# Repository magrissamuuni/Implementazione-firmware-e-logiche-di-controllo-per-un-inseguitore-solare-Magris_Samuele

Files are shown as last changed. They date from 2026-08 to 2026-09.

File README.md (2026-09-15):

Progetto sviluppato nell'ambito della tesi di laurea triennale
Dipartimento di Ingegneria dell'Informazione, Università degli Studi di Padova. 
Relatore: Prof. Damiano Varagnolo.

## Indice

- [Introduzione](#introduzione)
- [Obiettivi](#obiettivi)
- [Progettazione 3D](#progettazione-3d)
- [Hardware](#hardware)
- [Firmware](#firmware)
- [Interfaccia web](#interfaccia-web)
- [Prototipo](#prototipo)
- [Stampa Definitiva](#stampa-definitiva)
- [Metodologia sperimentale](#metodologia-sperimentale)
- [Design of Experiments](#design-of-experiments)
- [Confronto](#confronto)
- [Documentazione](#documentazione)
## Introduzione
Le fonti rinnovabili di energia sono viste come un'alternativa affidabile ai combustibili fossili grazie alla loro capacità di essere inesauribili.
L'energia solare fotovoltaica è una delle fonti rinnovabili più a portata di mano rispetto all'energia geotermica, idrica, bioenergia oppure eolica.
Massimizzare il tempo passato perpendicolarmente al sole è uno dei metodi migliori per massimizzare l'efficienza di un pannello fotovoltaico
(dimostrabile secondo la formula $$P = G \cdot A \cdot \eta \cdot \cos(\theta)$$)

Per fare ciò, sistemi di tracciamento permettono ai pannelli solari di rimanere perpendicolari ai raggi solari per la maggior parte della giornata.
Lo scopo di questo progetto è quello di sviluppare un prototipo bi-assiale a scala ridotta di un sistema di tracciamento solare mediante l'uso di fotoresistenze per tracciare la posizione del sole.

## Obiettivi

L'obiettivo è quello di creare un sistema indipendente in grado di autosostenersi.
Il sistema deve essere in grado di:
- riconoscere la posizione del punto di massima luminosità e orientare il pannello verso di esso;
- evitare micro-movimenti una volta raggiunto tale punto (causati da valori diversi sulle fotoresistenze).

Il firmware deve:
- implementare una interfaccia per l'utilizzo del sistema;
- implementare un controllore PID e permetterne la modifica dei parametri;
- raccogliere le informazioni e i dati riguardo a: errori dei servomotori, luminosità delle fotoresistenze e parametri dei pannelli fotovoltaici;
- gestire il movimento dei servo-motori;

## Progettazione 3D
Il sistema meccanico è stato progettato tramite l'utilizzo di Fusion 360.
E' progettato per permettere l'utilizzo di due servomotori SG90 che consentono il movimento bi-assiale. Per ricavare i dati di puntamento tramite le fotoresistenze è stata realizzata una struttura a croce che proietta un'ombra sulle LDR: quando il pannello è orientato perpendicolarmente al sole, l'ombra cade in modo simmetrico su tutti e quattro i sensori, azzerando la differenza di illuminamento tra loro:

Il sistema composto da:
- un ingranaggio con due strutture a forcella;
  <br>
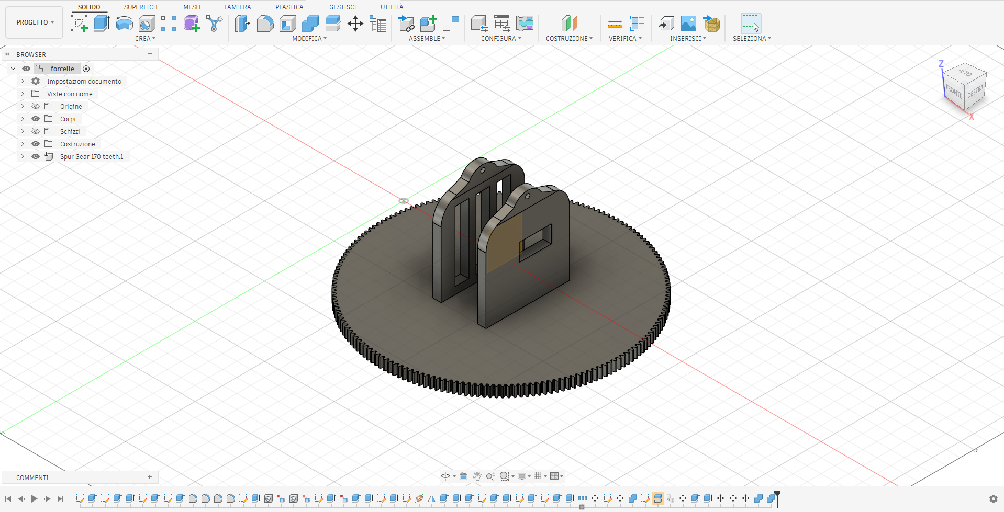
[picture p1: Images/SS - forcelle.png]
  
- una croce per permettere di proiettare ombre sulle LDR;
  <br>
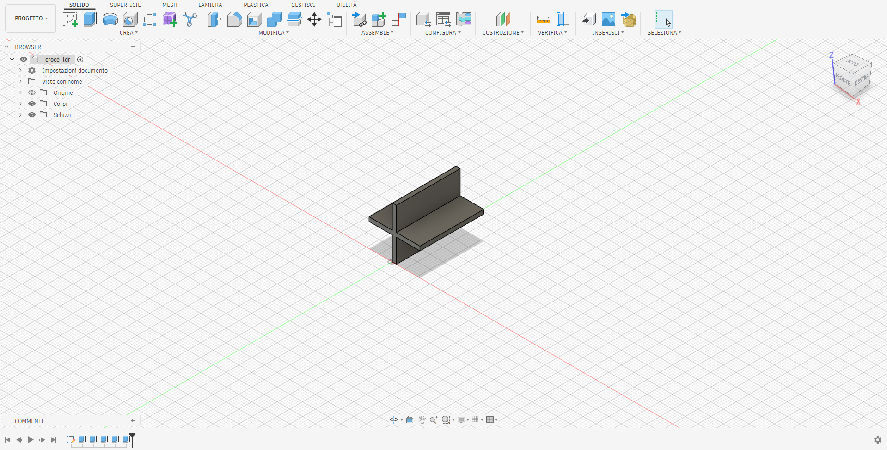
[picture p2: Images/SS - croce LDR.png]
  
- due pignoni, che collegano li SG90 al resto della struttura;
  <br>
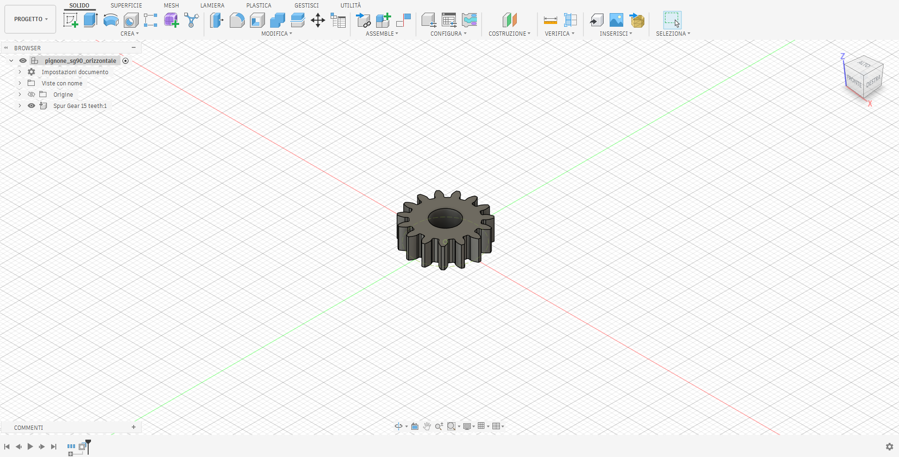
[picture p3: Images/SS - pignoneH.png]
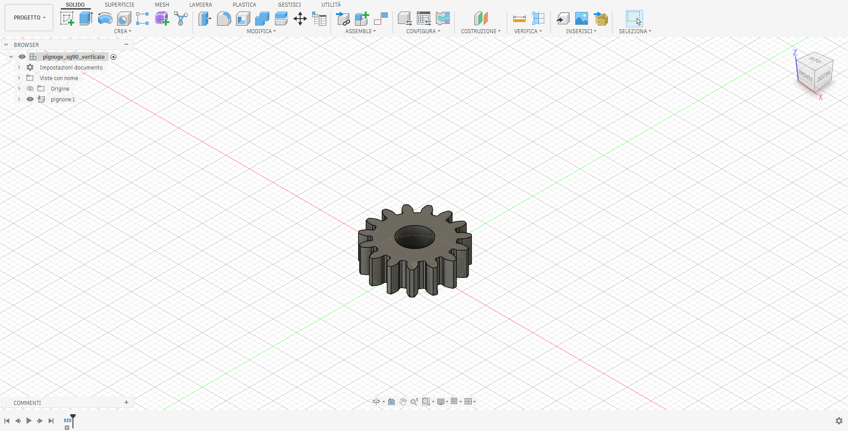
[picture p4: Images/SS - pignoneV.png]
     
- una struttura rettangolare dove risiede il pannello;
  <br>
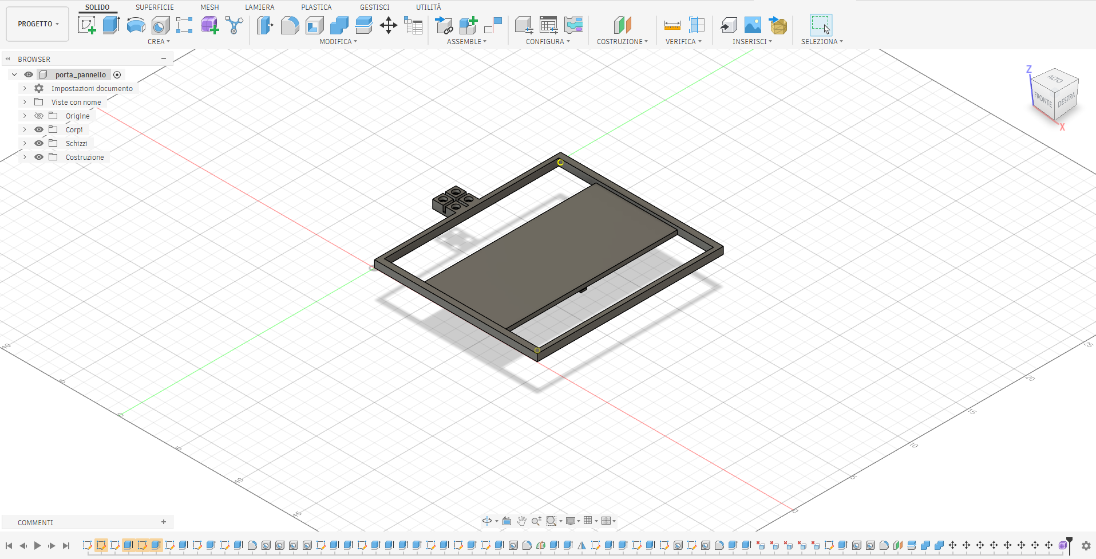
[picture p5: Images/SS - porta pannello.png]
    
- un semi-ingranaggio;
  <br>
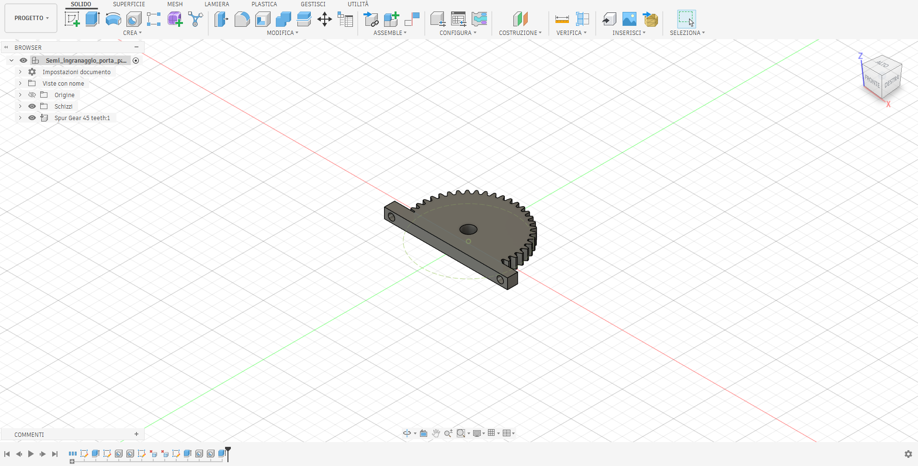
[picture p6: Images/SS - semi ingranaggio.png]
  
- una struttura di base. su cui poggia l'intero sistema.
  <br>
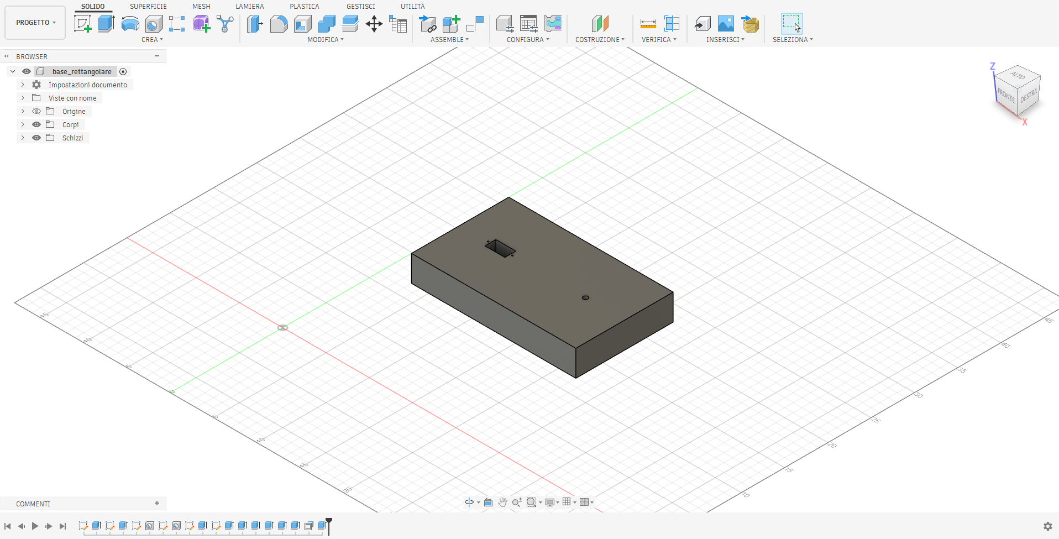
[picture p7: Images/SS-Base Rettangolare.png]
    

## Hardware

- Microcontrollore: ESP32 WROOM [ESP32](DataSheet/esp32-wroom-32_datasheet_en.pdf)
- Sensori: 4 fotoresistenze (LDR) [LDR](DataSheet/GL55-LDR%20DataSheet.pdf)
- Attuatori: 2 servomotori [SG90](DataSheet/SG90%20DataSheet.pdf)
- Batteria: 1 batteria ricaricabile al litio [103450](DataSheet/Battery%203.7%20V%202000mAh%20103450%20DataSheet.pdf)
- Ricarica e protezione: 1 modulo di ricarica con 1 chip di protezione [TP5046](DataSheet/TP4056%20(modulo%20ricarica)%20DataSheet.pdf) [DW01A](DataSheet/DW01A%20(chip%20protezione)%20DataSheet.pdf)
- Lettore Voltaggio/Corrente: [INA219](DataSheet/ina219%20(current%20power%20monitor)%20DataSheet.pdf)
- Modulo Step-UP: 1 modulo [MT3608](DataSheet/MT3608%20(step%20up)%20DataSheet.pdf)
- Pannello solare: 5V

Il circuito è alimentato da un pannello solare in silicio policristallino da 5V con potenza massima erogabile di 2.5W. Questo è collegato ad un modulo di ricarica TP4056 che permette la ricarica di una batteria LiPo 3.7V 2000mAh

Un convertitore step-up MT3608 porta la tensione della batteria al livello richiesto dal circuito ovvero 5V. Quest’ultimo alimenta l’ESP32 e quindi l’intero circuito

Sono state utilizzate 4 fotoresistenze (LDR) per rilevare la posizione del sole. Tramite l’ESP32 le fotoresistenze indicavano al sistema dove posizionarsi tramite l’utilizzo di due servomotori SG90

### Mappa dei pin

- Servo orizzontale (H) = 19
- Servo verticale (V) = 18 
- LDR Alto-Sinistra (TL) = 35
- LDR Alto-Destra (TR) = 33
- LDR Basso-Sinistra (BL) = 34
- LDR Basso-Destra (BR) = 32
- Tensione pannello solare = 36

## Firmware

File: [`src/main.cpp`](src/main.cpp) + [`include/webpage.h`](include/webpage.h)

### Librerie richieste (Arduino IDE / PlatformIO)

- `WiFi.h`, `WebServer.h`, `Preferences.h`
- `ESP32Servo`
- `PID_v1`

### Funzionalità principali

- Controllo PID reale su entrambi gli assi
- Autotuning automatico dei guadagni PID via relay feedback
  (metodo di Åström–Hägglund + formule di Ziegler-Nichols)
- Calibrazione automatica dei 4 sensori LDR
- Logging su buffer con esportazione CSV
- Persistenza dei parametri in NVS

### Come Avviare

1. Apri `firmware/main.cpp` in Arduino IDE o PlatformIO
2. Installa le librerie elencate sopra dal Library Manager
3. Seleziona la scheda ESP32 corretta e la porta seriale
4. Carica il firmware

All'avvio l'ESP32 crea una rete Wi-Fi propria:

- **SSID**: `SolarTracker-ESP32`
- **Password**: `12345678`

## Interfaccia web

Connettiti alla rete Wi-Fi del tracker e apri `http://192.168.4.1` dal
browser. L'interfaccia mostra in tempo reale: telemetria del pannello solare,
letture dei 4 LDR, stato del controllo PID, e permette di cambiare modalità,
controllare manualmente i motori, tarare il PID, calibrare i sensori e
scaricare i log come CSV.

## Prototipo

Il sistema è stato inizialmente stampato in  PLA, il quale inizia a subire deformazioni strutturali e a perdere la propria rigidità geometrica già all’interno dell’intervallo termico compreso tra i 50 °C e i 60 °C. 
Si è quindi optato per il PETG, in grado di garantire una stabilità dimensionale anche in condizioni di calore moderato (fino ai 70 °C  - 75°C) superando così i limiti del PLA. Inoltre, presenta una maggiore opacità alla luce rispetto al PLA.

Il circuito è stato assemblato e saldato manualmente con alcuni errori di collegamento verificatisi e successivamente corretti.
E' stato successivamente validato funzionalmente prima dei test firmware.

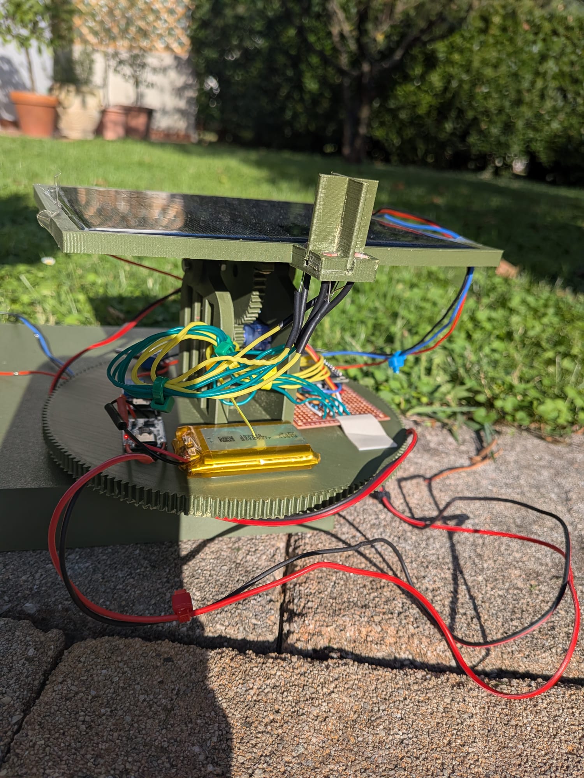
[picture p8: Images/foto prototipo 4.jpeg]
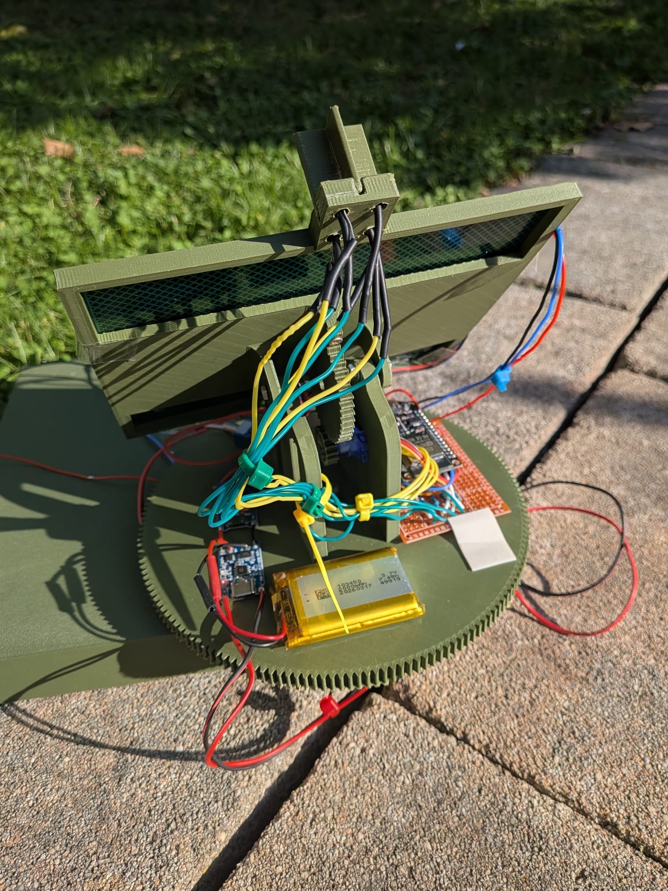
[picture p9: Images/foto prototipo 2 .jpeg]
 
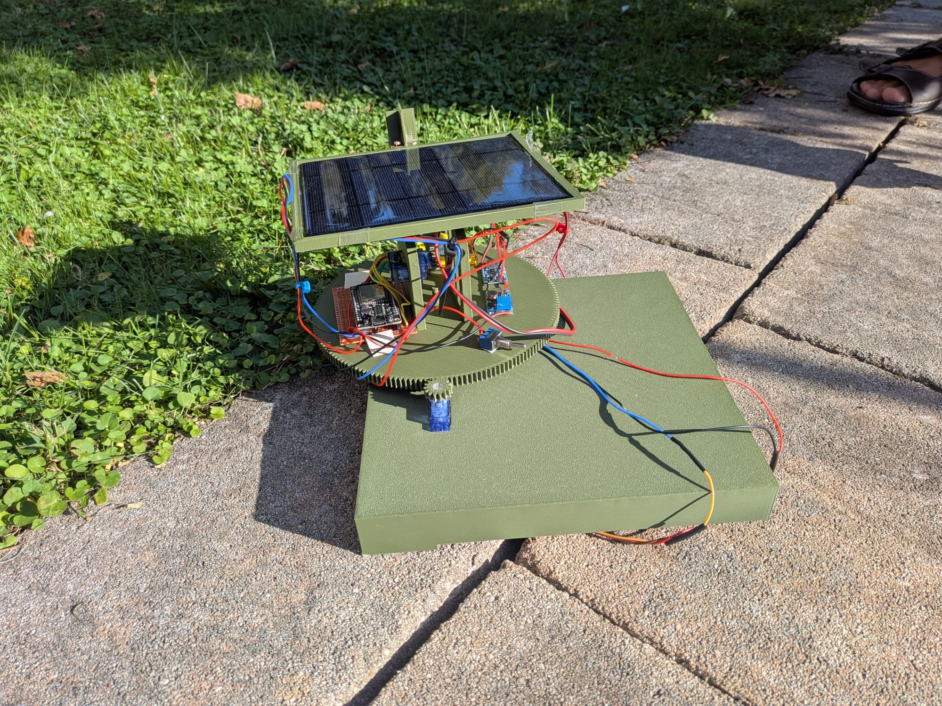
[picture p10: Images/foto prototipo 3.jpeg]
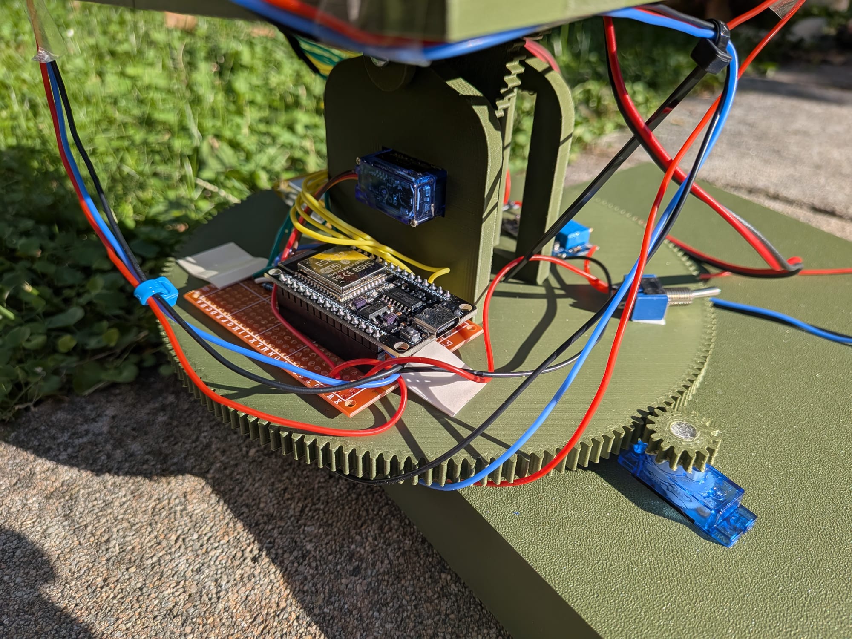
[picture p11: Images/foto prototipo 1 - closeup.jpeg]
 

Il sistema risulta funzionale ma non esponibile al sola dato il materiale utilizzato. Occorre quindi una ristampa.

## Stampa Definitiva
La versione finale è stata stampata in PETG e non ha più presentato i problemi di deformazione termica riscontrati con il PLA, confermando la stabilità strutturale della soluzione adottata. <br> <br>
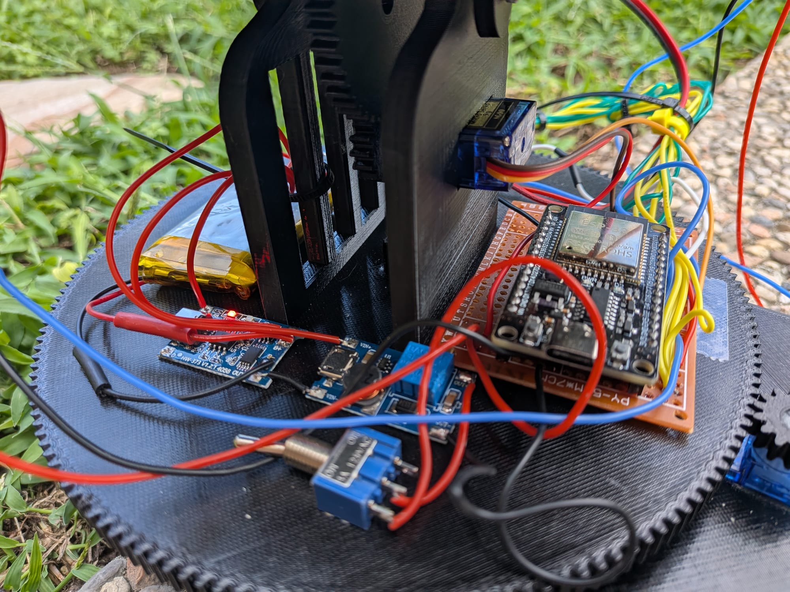
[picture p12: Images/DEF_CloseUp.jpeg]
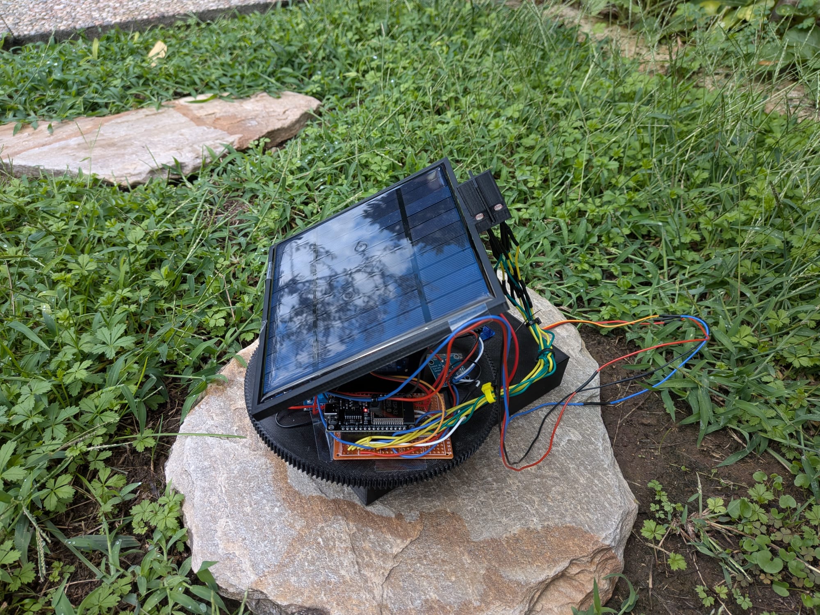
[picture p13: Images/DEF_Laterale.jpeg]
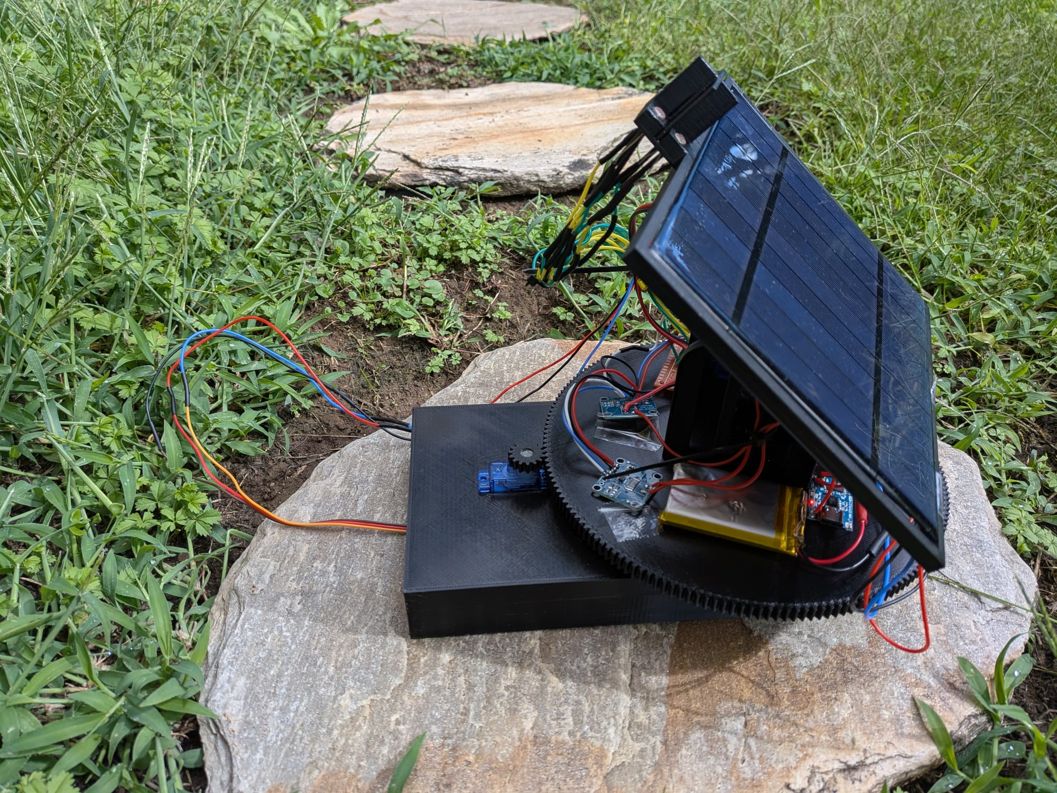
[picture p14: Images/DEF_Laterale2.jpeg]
   

## Metodologia sperimentale

I guadagni PID (Kp/Ki/Kd) **non** sono variabili sperimentali del DOE: sono
tarati a parte tramite il metodo di Åström-Hägglund. Da questo otteniamo:

$$K_u = \frac{1}{|G(j\omega_u)|} = \frac{4d}{\pi a}$$

$$P_u = \frac{2\pi}{\omega_u}$$

Tramite le tabelle di Ziegler-Nichols:

$$K_p = 0.6K_u \qquad T_i = \frac{P_u}{2} \qquad T_d = \frac{P_u}{8}$$

$$K_p = 0.6K_u \qquad K_i = \frac{2K_p}{P_u} \qquad K_d = \frac{K_p P_u}{8}$$

A differenza dei modelli teorici in tempo continuo, il microcontrollore elabora i segnali dei sensori a intervalli di tempo regolari e definiti (tempo di campionamento 𝑇𝑠=50𝑚𝑠)

## Design of Experiments

| Variabile | ANOVA F | ANOVA p | Pendenza | R² | Regressione p |
|---|---|---|---|---|---|
| Errore residuo H | 2.319 | 0.112 | +0.075 | 0.024 | 0.328 |
| Errore residuo V | 2.329 | 0.111 | +0.010 | 0.001 | 0.884 |
| Overshoot H | 1.940 | 0.157 | −0.435 | 0.037 | 0.222 |
| Overshoot V | 0.913 | 0.410 | +0.123 | 0.007 | 0.609 |
| Tempo di assestamento H | 2.389 | 0.105 | −50.68 | 0.079 | 0.072 |
| Tempo di assestamento V | 1.601 | 0.215 | −42.82 | 0.069 | 0.092 |

Nessuna delle variabili di risposta ha raggiunto la soglia di significatività, né tramite ANOVA né tramite regressione lineare.
Nonostante il disegno sperimentale esteso fosse dimensionato per garantire l'80% di potenza rispetto all'effetto stimato nella fase preliminare, l'effetto osservato nel campione esteso è risultato sostanzialmente più piccolo della stima iniziale. 
<br>
Due sensori LDR saturano al valore massimo e il comportamento è coerente con un sottodimensionamento del partitore resistivo che non garantisce un margine sufficiente in condizioni di elevata luminosità.
Con due sensori bloccati allo stesso valore le formule di errore si riducono algebricamente in modo tale che errore H ed errore V diventano l'uno l'esatto opposto dell'altro

## Confronto

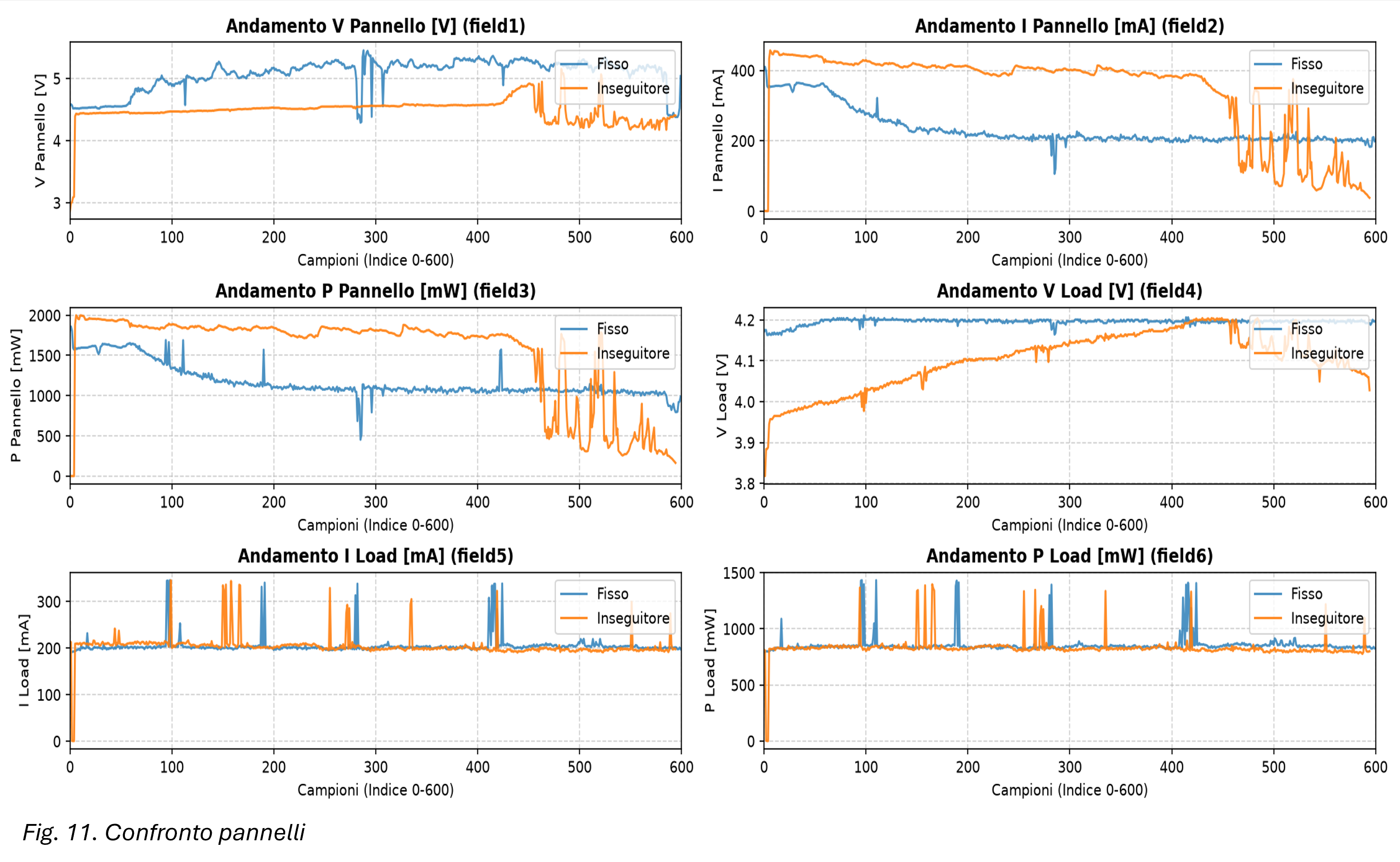
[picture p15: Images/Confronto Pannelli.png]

L'inseguimento biassiale garantisce un'erogazione media di 1.8 W - 2.0 W, incrementando la resa rispetto all'installazione statica di circa il 50-70% nello stesso intervallo.
In entrambi i casi il consumo del carico è il medesimo. 
I campioni 450-600 dell’inseguitore riflettono un annuvolamento avvenuto durante la raccolta dati.

## Documentazione
[ESP32](DataSheet/esp32-wroom-32_datasheet_en.pdf)
[LDR](DataSheet/GL55-LDR%20DataSheet.pdf)
[SG90](DataSheet/SG90%20DataSheet.pdf)
[103450](DataSheet/Battery%203.7%20V%202000mAh%20103450%20DataSheet.pdf)
[TP5046](DataSheet/TP4056%20(modulo%20ricarica)%20DataSheet.pdf) [DW01A](Datasheet/DW01A%20(chip%20protezione)%20DataSheet.pdf)
[INA219](DataSheet/ina219%20(current%20power%20monitor)%20DataSheet.pdf)
[MT3608](DataSheet/MT3608%20(step%20up)%20DataSheet.pdf)

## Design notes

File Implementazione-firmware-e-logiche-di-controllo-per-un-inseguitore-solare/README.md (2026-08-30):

# Solar Tracker Biassiale con ESP32

Inseguitore solare a due assi (orizzontale/verticale) basato su microcontrollore
ESP32, con controllo PID reale, autotuning automatico via relay feedback,
interfaccia web integrata e un set di script Python per l'analisi statistica
delle prove sperimentali (Design of Experiments).

Progetto sviluppato nell'ambito della tesi di laurea triennale
 Dipartimento di Ingegneria dell'Informazione,
Università degli Studi di Padova. Relatore: Prof. Damiano Varagnolo.

## Indice

- [Hardware](#hardware)
- [Firmware](#firmware)
- [Interfaccia web](#interfaccia-web)
- [Analisi dati](#analisi-dati)
- [Metodologia sperimentale](#metodologia-sperimentale)
- [Struttura del repository](#struttura-del-repository)
- [Documentazione](#documentazione)
- [Licenza](#licenza)

## Hardware

- Microcontrollore: ESP32 WROOM [ESP32](Datasheet/esp32-wroom-32_datasheet_en.pdf)
- Sensori: 4 fotoresistenze (LDR) [LDR](Datasheet/GL55-LDR%20DataSheet.pdf)
- Attuatori: 2 servomotori [SG90](Datasheet/SG90%20DataSheet.pdf)
- Batteria: 1 batteria ricaricabile al litio [103450](Datasheet/Battery%203.7%20V%202000mAh%20103450%20DataSheet.pdf)
- Ricarica e protezione: 1 modulo di ricarica con 1 chip di protezione [TP5046](Datasheet/TP4056%20(modulo%20ricarica)%20DataSheet.pdf) [DW01A](Datasheet/DW01A%20(chip%20protezione)%20DataSheet.pdf)
- Lettore Voltaggio/Corrente: [INA219](Datasheet/ina219%20(current%20power%20monitor)%20DataSheet.pdf)
- Modulo Step-UP: 1 modulo [MT3608](Datasheet/MT3608%20(step%20up)%20DataSheet.pdf)
- Pannello solare: 5V

### Mappa dei pin

Servo orizzontale (H) = 19 
Servo verticale (V) = 18  
LDR Alto-Sinistra (TL) = 35
LDR Alto-Destra (TR) = 33
LDR Basso-Sinistra (BL) = 34
LDR Basso-Destra (BR) = 32
Tensione pannello solare = 36 

## Firmware

File: [`firmware/main.cpp`](firmware/main.cpp) + [`firmware/webpage.h`](firmware/webpage.h)

### Librerie richieste (Arduino IDE / PlatformIO)

- `WiFi.h`, `WebServer.h`, `Preferences.h`
- `ESP32Servo`
- `PID_v1`

### Funzionalità principali

- Controllo PID reale su entrambi gli assi (filtro passa-basso sulle letture
  LDR, anti-windup, uscita continua sui servo)
- Autotuning automatico dei guadagni PID via relay feedback
  (metodo di Åström–Hägglund + formule di Ziegler-Nichols)
- Calibrazione automatica dei 4 sensori LDR
- Logging su buffer con esportazione CSV
- Persistenza dei parametri in NVS

### Come Avviare

1. Apri `firmware/main.cpp` in Arduino IDE o PlatformIO
2. Installa le librerie elencate sopra dal Library Manager
3. Seleziona la scheda ESP32 corretta e la porta seriale
4. Carica il firmware

All'avvio l'ESP32 crea una rete Wi-Fi propria:

- **SSID**: `SolarTracker-ESP32`
- **Password**: `12345678`

## Interfaccia web

Connettiti alla rete Wi-Fi del tracker e apri `http://192.168.4.1` dal
browser. L'interfaccia mostra in tempo reale: telemetria del pannello solare,
letture dei 4 LDR, stato del controllo PID, e permette di cambiare modalità,
controllare manualmente i motori, tarare il PID, calibrare i sensori e
scaricare i log come CSV.

## Metodologia sperimentale

//TODO

I guadagni PID (Kp/Ki/Kd) **non** sono variabili sperimentali del DOE: sono
tarati a parte tramite autotuning a relay feedback, avendo un metodo di
teoria dei controlli per calcolarli direttamente. 

Risultati completi in:
//TODO

## Struttura del repository

```
solar-tracker-esp32/
├── firmware/
│   ├── main.cpp          # firmware ESP32
│   └── webpage.h         # interfaccia web (HTML/CSS/JS)
├── analysis/
│   ├── analyze_log.py               # estrazione metriche da log grezzi
│   ├── anova_doe.py                 # analisi statistica del DOE
│   ├── analyze_energy_comparison.py # confronto energetico tracker/fisso
│   └── requirements.txt
├── data/
│   ├── doe_zona_morta/   
│   └── riepilogo_doe.csv # riepilogo aggregato 
└── docs/
    └── matrice_DOE_randomizzata.csv        # ordine di esecuzione delle prove
```

## Documentazione
 [ESP32](Datasheet/esp32-wroom-32_datasheet_en.pdf)
[LDR](Datasheet/GL55-LDR%20DataSheet.pdf)
[SG90](Datasheet/SG90%20DataSheet.pdf)
[103450](Datasheet/Battery%203.7%20V%202000mAh%20103450%20DataSheet.pdf)
[TP5046](Datasheet/TP4056%20(modulo%20ricarica)%20DataSheet.pdf) [DW01A](Datasheet/DW01A%20(chip%20protezione)%20DataSheet.pdf)
[INA219](Datasheet/ina219%20(current%20power%20monitor)%20DataSheet.pdf)
[MT3608](Datasheet/MT3608%20(step%20up)%20DataSheet.pdf)

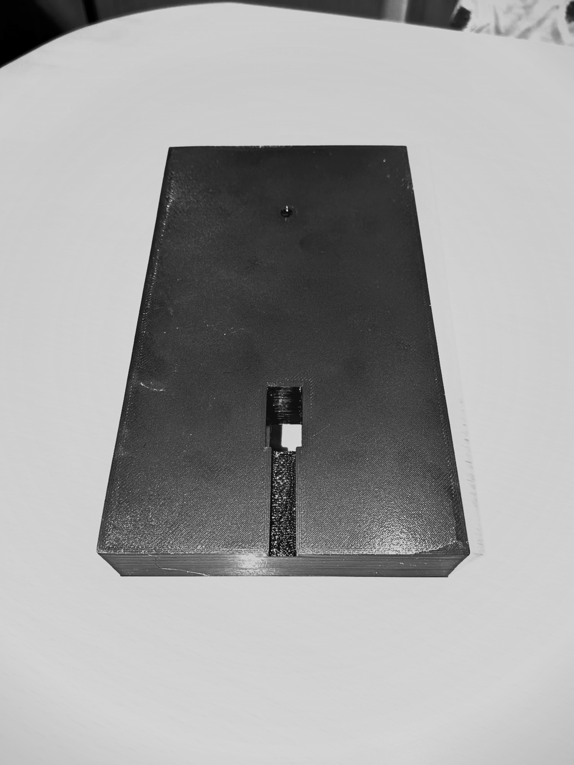
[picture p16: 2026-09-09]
Images/05-base-vista-superiore.png

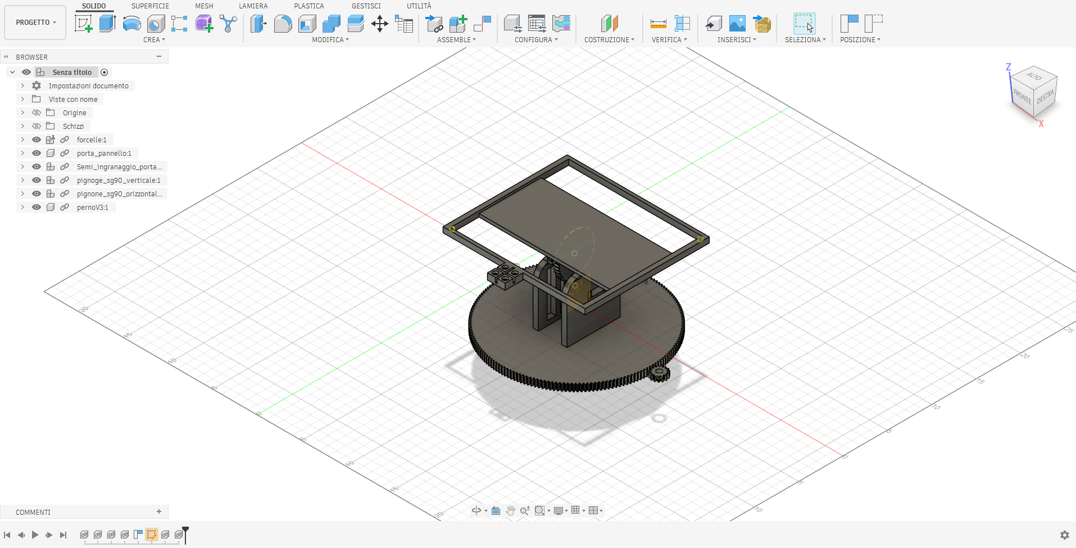
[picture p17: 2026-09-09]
Images/SS - insieme.png

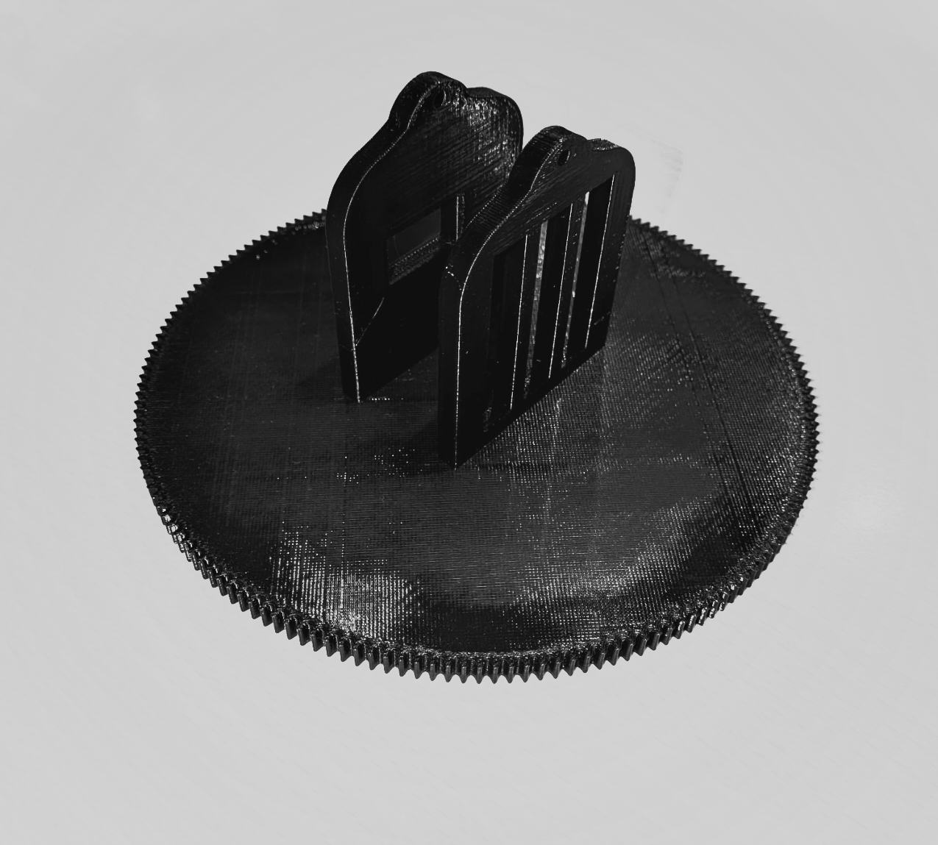
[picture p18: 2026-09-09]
Images/04-corona-dentata-forcelle.png

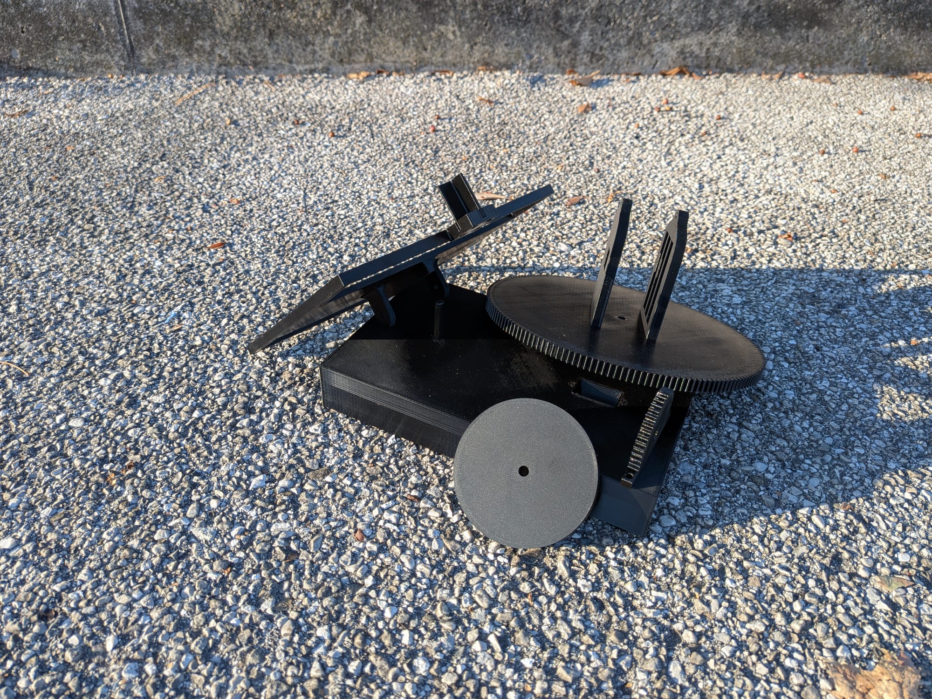
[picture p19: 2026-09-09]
Images/foto pezzi definitivi uniti.jpeg

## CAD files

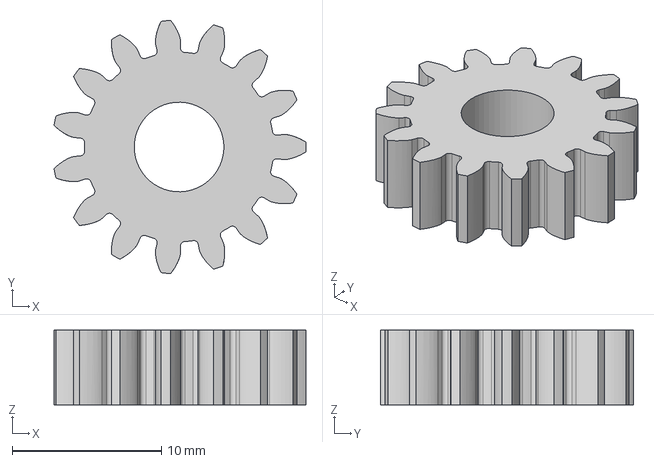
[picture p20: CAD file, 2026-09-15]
File3D/pignoge_sg90_verticale.step
16.9 x 17.0 x 5.00 mm

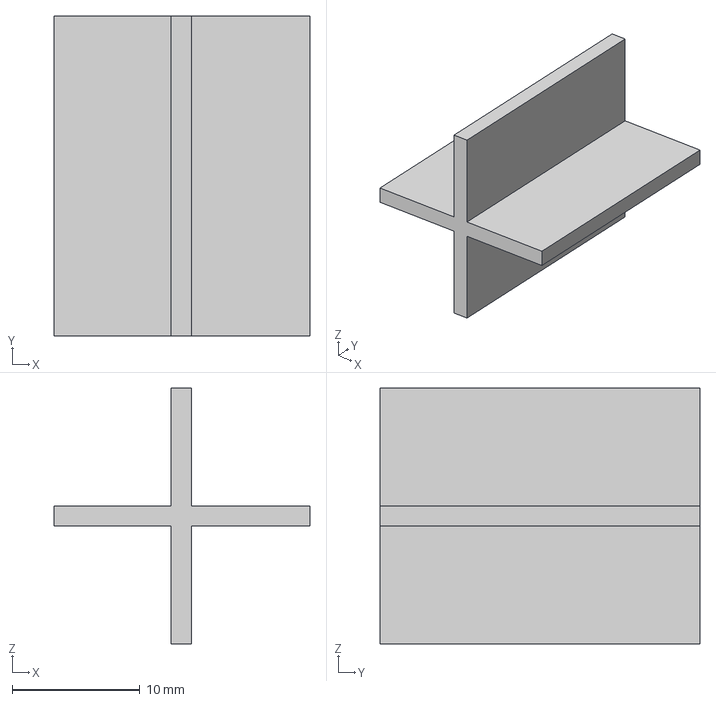
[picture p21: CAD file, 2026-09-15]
File3D/croce_ldr.step
20.0 x 25.0 x 20.0 mm

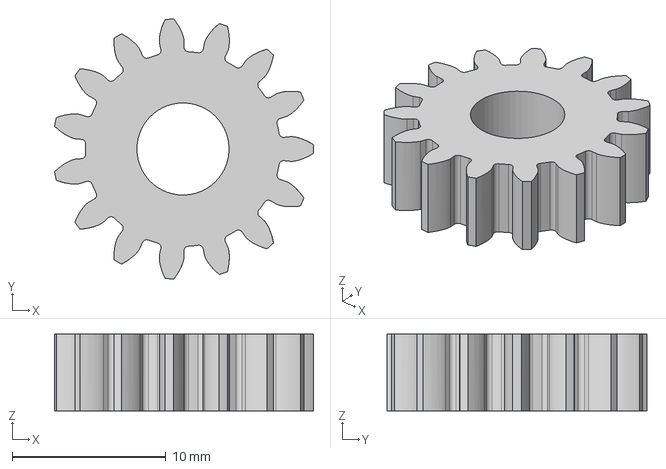
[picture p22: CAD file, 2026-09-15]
File3D/pignone_sg90_orizzontale.step
16.9 x 17.0 x 5.00 mm

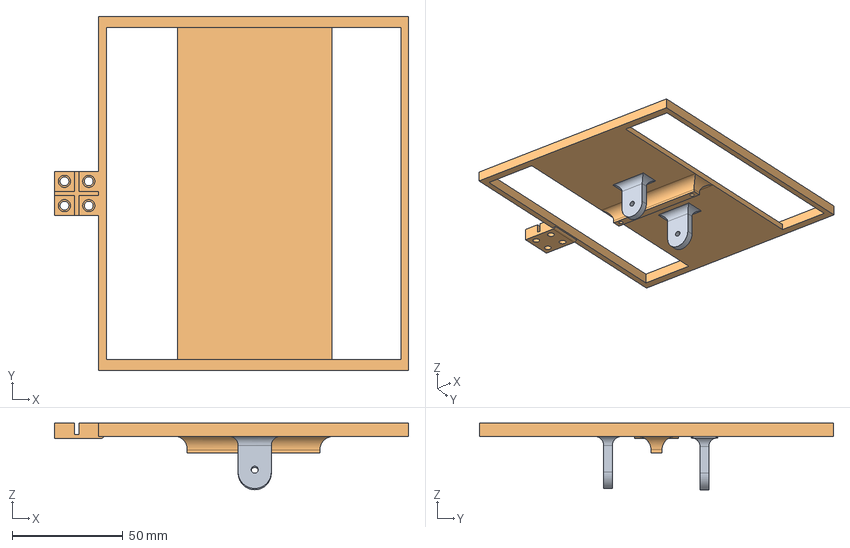
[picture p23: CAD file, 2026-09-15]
File3D/porta_pannello.step
160.0 x 160.0 x 30.1 mm

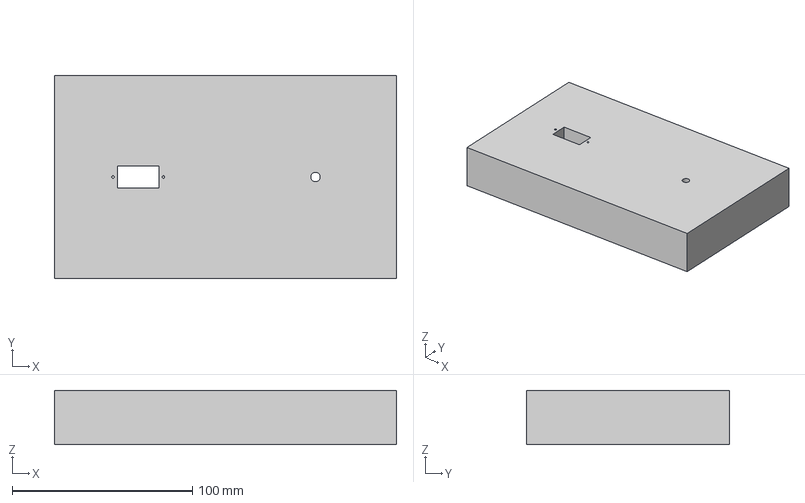
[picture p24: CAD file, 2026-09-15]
File3D/base_rettangolare.step
190.0 x 112.5 x 30.0 mm

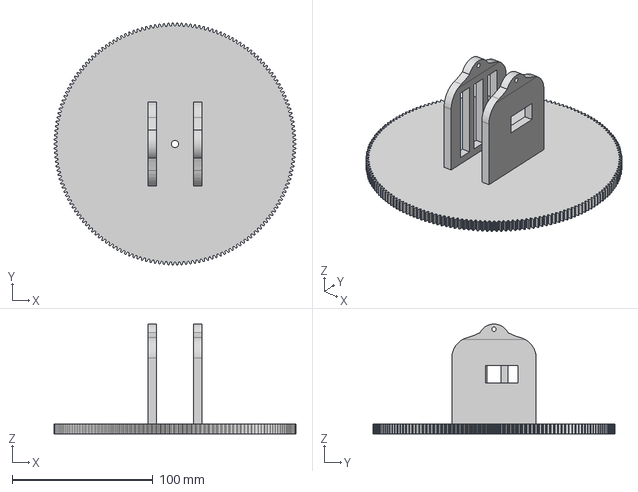
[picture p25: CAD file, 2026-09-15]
File3D/forcelle.step
172.0 x 172.0 x 78.2 mm

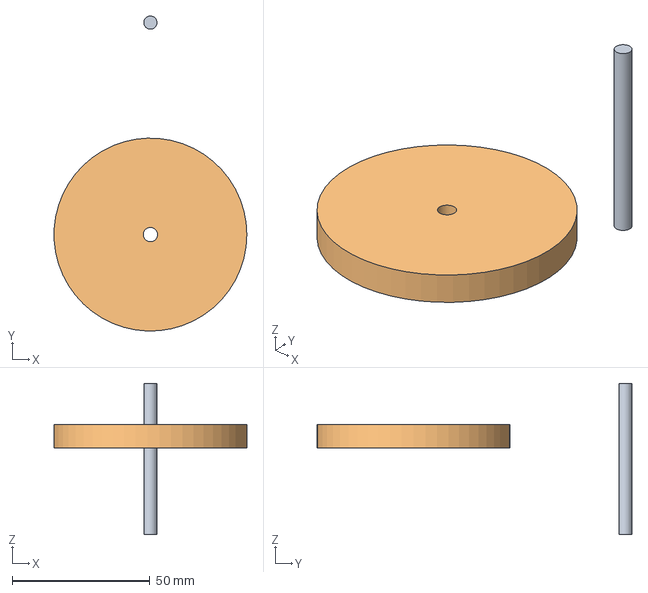
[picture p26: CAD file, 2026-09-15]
File3D/pernoV3.step
70.0 x 114.4 x 55.0 mm

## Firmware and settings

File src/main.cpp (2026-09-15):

#include <Arduino.h>
#include <WiFi.h>
#include <WebServer.h>
#include <ESP32Servo.h>
#include <PID_v1.h>
#include <Preferences.h>
#include <Wire.h>
#include <Adafruit_INA219.h>
#include <HTTPClient.h>
#include "webpage.h"

// Modalità di Funzionamento
enum OperatingMode {
  MODE_AUTO,
  MODE_MANUAL,
  MODE_AUTOTUNE,
  MODE_DOE
};

OperatingMode currentMode = MODE_AUTO;
String modeString = "auto";

// Configurazione Access Point Wi-Fi
const char* ap_ssid = "SolarTracker-ESP32";
const char* ap_password = "12345678";

const char* sta_ssid = "TUO_SSID";
const char* sta_password = "TUA_PASSWORD";
const char* thingspeakApiKey = "TUO_API";
const unsigned long THINGSPEAK_INTERVAL_MS = 30000UL;
unsigned long lastThingspeakSendMillis = 0;
bool thingspeakLastSendOk = false;

WebServer server(80);

// Pin Servo 360 Continuous
const int pinServoH = 21; //21
const int pinServoV = 18; //18

Servo servoH;
Servo servoV;

// Valori di stop per servi 360 in microsecondi
int STOP_H_US = 1500; 
int STOP_V_US = 1500; 

// Pin Sensori LDR 
const int ldrTL = 35; // Top Left (Alto SX)
const int ldrTR = 33; // Top Right (Alto DX)
const int ldrBL = 32; // Bottom Left (Basso SX)
const int ldrBR = 34; // Bottom Right (Basso DX)

// Pin Lettura Tensione Pannello Solare
const int pinSolarVolt = 36;

const int pinSDA = 4;
const int pinSCL = 5;

uint8_t inaAddrPanel = 0x40;
uint8_t inaAddrLoad = 0x41;
Adafruit_INA219 *inaPanel = nullptr;
Adafruit_INA219 *inaLoad = nullptr;
bool inaPanelOk = false;
bool inaLoadOk = false;

float inaPanelV = 0.0f, inaPanelI_mA = 0.0f, inaPanelP_mW = 0.0f;
float inaLoadV = 0.0f, inaLoadI_mA = 0.0f, inaLoadP_mW = 0.0f;
float realEnergyWh = 0.0f;
float efficienzaPercent = 0.0f;

// Parametri PID
double setpointH = 0, inputH, outputH;
double setpointV = 0, inputV, outputV;
double Kp = 0.5, Ki = 0.0, Kd = 0.05;

PID pidH(&inputH, &outputH, &setpointH, Kp, Ki, Kd, REVERSE);
PID pidV(&inputV, &outputV, &setpointV, Kp, Ki, Kd, REVERSE);

// True quando il rispettivo PID sta effettivamente guidando il motore 
bool pidActiveH = false;
bool pidActiveV = false;

// Soglie operative
int sogliaNotte = 100;
int zonaMorta = 350; // Zona morta per evitare oscillazioni e pendolamento
int sogliaPuntoMorto = 700; // Soglia per rilevare il punto morto diagonale (saddle point)


bool puntoMortoAbilitato = true;

const float DEADZONE_HYSTERESIS_RATIO = 0.6f;

// Velocità ridotta in AUTO per test 
int maxAutoSpeed = 3; // Limite di velocità per rotazione fluida e precisa in AUTO

// Variabili per Controllo Manuale
int manualVelH = 0; // -15 a +15
int manualVelV = 0; // -15 a +15

const unsigned long MANUAL_TIMEOUT_MS = 2000;
unsigned long lastManualCmdMillis = 0;

// Telemetria Pannello Solare
float solarVoltage = 0.0;
float solarCurrent = 0.0;
float solarPower = 0.0;
float totalEnergyWh = 0.0;
unsigned long lastEnergyCalc = 0;

// Valori LDR (filtrati) e Diagonali
int valTL = 0, valTR = 0, valBL = 0, valBR = 0;
int valDiag1 = 0;      // Diagonale 1: TL + BR
int valDiag2 = 0;      // Diagonale 2: TR + BL
int diffDiagonali = 0; // Differenza (Diag1 - Diag2)
int mediaTotale = 0;
bool puntoMortoAttivo = false; // True se rilevato punto morto diagonale
bool isAutotuning = false;     // True durante il test di autotuning PID (relay feedback)

const float LDR_FILTER_TAU_S = 0.15f;
float filtTL = 0, filtTR = 0, filtBL = 0, filtBR = 0;
bool ldrFilterInit = false;

// Fattori di calibrazione per compensare le differenze di sensibilità tra i 4 LDR
float calTL = 1.0f, calTR = 1.0f, calBL = 1.0f, calBR = 1.0f;

const int ADC_OVERSAMPLE_COUNT = 4;

// Risparmio energetico
bool servosPowerSaved = false;

int lastPulseHus = 1500;
int lastPulseVus = 1500;

// Preferences NVS
Preferences prefs;
unsigned long lastEnergySaveMs = 0;
const unsigned long ENERGY_SAVE_INTERVAL_MS = 5UL * 60UL * 1000UL; // ogni 5 min, per limitare l'usura della flash

// Stima cinematica della posizione e controllo di velocità proporzionale
float posH = 0.0f; // Posizione stimata H (0°..360°)
float posV = 0.0f; // Posizione stimata V (-60°..+60°)
const float SPEED_TO_DEG_PER_SEC = 5.0f;
unsigned long lastPosUpdate = 0;
double activeSpeedH = 0;
double activeSpeedV = 0;

const float V_ANGLE_MIN = -60.0f;
const float V_ANGLE_MAX = 60.0f;
bool vAxisAtLimit = false;

// Logging in RAM con esportazione CSV
struct LogSample {
  uint32_t t;
  int16_t errH, errV, pulseH, pulseV, tl, tr, bl, br;
  int16_t vPanel_mV, iPanel_mA, vLoad_mV, iLoad_mA;
};
const int MAX_LOG_SAMPLES = 1500;
LogSample logBuffer[MAX_LOG_SAMPLES];
int logCount = 0;
bool loggingActive = false;
unsigned int logIntervalMs = 100;
unsigned long logStartMillis = 0;
unsigned long lastLogSampleMillis = 0;

const double RELAY_AMPLITUDE = 2.0;         // "d": velocità fissa comandata dal relè
const double RELAY_HYSTERESIS = 40.0;       // banda morta di commutazione
const int RELAY_DISCARD_HALFCYCLES = 6;     // scarta il transitorio iniziale 
const int RELAY_COLLECT_HALFCYCLES = 14;    //  ~7 cicli per la stima
const unsigned long RELAY_SAMPLE_INTERVAL_MS = 20;
const unsigned long RELAY_TIMEOUT_MS = 45000; // failsafe

struct RelayAxisState {
  int relayDir = 1;
  double halfCyclePeak = 0;
  unsigned long lastSwitchMs = 0;
  int halfCycleIndex = 0;
  double posPeakSum = 0; int posPeakCount = 0;
  double negPeakSum = 0; int negPeakCount = 0;
  unsigned long periodSumMs = 0; int periodCount = 0;
  bool done = false;
};

struct DoeRun {
  int run;
  int deadzone;
  int replica;
  String filename;
};
const int MAX_DOE_RUNS = 60;
DoeRun doeRuns[MAX_DOE_RUNS];
int doeRunCount = 0;
int doeCurrentIndex = -1;
bool doeActive = false;
bool doeRunReady = false;
unsigned long doeRunDurationMs = 60000;
unsigned long doeRunStartMillis = 0;
bool doeKicking = false;
unsigned long doeKickStartMillis = 0;
const int DOE_KICK_SPEED = 8;
const unsigned long DOE_KICK_DURATION_MS = 2000;

// Dichiarazioni Funzioni
int speedToPulseUS(double speed, int stopUS);
void setServoH(double speed);
void setServoV(double speed);
void stopServos();
void powerSaveServos();
void resetPID(PID &pid);
int readLDROversampled(int pin);
void calibrateLDRs();
void loadSettingsFromNVS();
void saveSettingsToNVS();
void relayStep(RelayAxisState &st, double error, unsigned long nowMs, void (*setServo)(double));
bool runRelayAutotune(double &outKp, double &outKi, double &outKd);
void runAutoTracking();
void initINA();
void readINASensors();
void doeStartKick();
void doeBeginLogging(int idx);
bool doeGuard();
void setupWebServer();
void handleRoot();
void handleApiData();
void handleApiMode();
void handleApiControl();
void handleApiPID();
void handleApiCalibrate();
void handleApiResetPos();
void handleApiLogStart();
void handleApiLogStop();
void handleApiLogStatus();
void handleApiLogCsv();
void handleApiAutotune();
void handleApiInaConfig();
void handleApiInaScan();
void handleApiDoeUpload();
void handleApiDoeStart();
void handleApiDoeNext();
void handleApiDoeStop();
void handleApiDoeStatus();
void sendToThingSpeak();

int speedToPulseUS(double speed, int stopUS) {
  if (speed > 0.02) {
    return stopUS - (int)round(45 + speed * 25);
  } else if (speed < -0.02) {
    return stopUS + (int)round(45 + fabs(speed) * 25);
  }
  return stopUS;
}
void setServoH(double speed) {
  if (!servoH.attached()) {
    servoH.attach(pinServoH, 1000, 2000);
    servosPowerSaved = false;
  }
  lastPulseHus = speedToPulseUS(speed, STOP_H_US);
  servoH.writeMicroseconds(lastPulseHus);
  activeSpeedH = speed;
}

// Il servo verticale è montato fisicamente con orientamento invertito rispetto
// a quello orizzontale
void setServoV(double speed) {
  vAxisAtLimit = false;
  if (speed > 0 && posV >= V_ANGLE_MAX) {
    speed = 0;
    vAxisAtLimit = true;
  } else if (speed < 0 && posV <= V_ANGLE_MIN) {
    speed = 0;
    vAxisAtLimit = true;
  }
  if (!servoV.attached()) {
    servoV.attach(pinServoV, 1000, 2000);
    servosPowerSaved = false;
  }
  lastPulseVus = speedToPulseUS(-speed, STOP_V_US);
  servoV.writeMicroseconds(lastPulseVus);
  activeSpeedV = speed;
}

void stopServos() {
  setServoH(0);
  setServoV(0);
}

// Stacca il segnale PWM dai servo dopo averli portati a zero
void powerSaveServos() {
  if (servosPowerSaved) return;
  stopServos();
  delay(20); // margine perché il servo elabori l'ultimo impulso neutro prima di staccare il PWM
  servoH.detach();
  servoV.detach();
  servosPowerSaved = true;
}


void resetPID(PID &pid) {
  pid.SetMode(MANUAL);
  pid.SetMode(AUTOMATIC);
}

int readLDROversampled(int pin) {
  long sum = 0;
  for (int i = 0; i < ADC_OVERSAMPLE_COUNT; i++) sum += analogRead(pin);
  return (int)(sum / ADC_OVERSAMPLE_COUNT);
}

void initINA() {
  if (inaPanel) { delete inaPanel; inaPanel = nullptr; }
  if (inaLoad) { delete inaLoad; inaLoad = nullptr; }
  inaPanel = new Adafruit_INA219(inaAddrPanel);
  inaLoad = new Adafruit_INA219(inaAddrLoad);
  inaPanelOk = inaPanel->begin(&Wire);
  inaLoadOk = inaLoad->begin(&Wire);
}

void readINASensors() {
  if (inaPanelOk) {
    inaPanelV = inaPanel->getBusVoltage_V() + (inaPanel->getShuntVoltage_mV() / 1000.0f);
    inaPanelI_mA = inaPanel->getCurrent_mA();
    inaPanelP_mW = inaPanel->getPower_mW();
  }
  if (inaLoadOk) {
    inaLoadV = inaLoad->getBusVoltage_V() + (inaLoad->getShuntVoltage_mV() / 1000.0f);
    inaLoadI_mA = inaLoad->getCurrent_mA();
    inaLoadP_mW = inaLoad->getPower_mW();
  }
}

void sendToThingSpeak() {
  WiFiClient client;
  HTTPClient http;
  String url = "http://api.thingspeak.com/update?api_key=" + String(thingspeakApiKey) +
    "&field1=" + String(inaPanelV, 3) +
    "&field2=" + String(inaPanelI_mA, 1) +
    "&field3=" + String(inaPanelP_mW, 1) +
    "&field4=" + String(inaLoadV, 3) +
    "&field5=" + String(inaLoadI_mA, 1) +
    "&field6=" + String(inaLoadP_mW, 1) +
    "&field7=" + String(efficienzaPercent, 1) +
    "&field8=" + String(realEnergyWh, 4);
  http.begin(client, url);
  int httpCode = http.GET();
  String payload = (httpCode == 200) ? http.getString() : "";
  thingspeakLastSendOk = (httpCode == 200) && (payload.toInt() > 0);
  http.end();
}

void loadSettingsFromNVS() {
  prefs.begin("solartrk", false);
  Kp = (double)prefs.getFloat("kp", 0.5f);
  Ki = (double)prefs.getFloat("ki", 0.0f);
  Kd = (double)prefs.getFloat("kd", 0.05f);
  zonaMorta = prefs.getInt("zonaMorta", 350);
  sogliaPuntoMorto = prefs.getInt("sogliaPM", 700);
  sogliaNotte = prefs.getInt("sogliaNotte", 100);
  puntoMortoAbilitato = prefs.getBool("pmAbil", true);
  calTL = prefs.getFloat("calTL", 1.0f);
  calTR = prefs.getFloat("calTR", 1.0f);
  calBL = prefs.getFloat("calBL", 1.0f);
  calBR = prefs.getFloat("calBR", 1.0f);
  totalEnergyWh = prefs.getFloat("energyWh", 0.0f);
  realEnergyWh = prefs.getFloat("realEnergyWh", 0.0f);
  inaAddrPanel = prefs.getUChar("inaAddrP", 0x40);
  inaAddrLoad = prefs.getUChar("inaAddrL", 0x41);
  prefs.end();
}

void saveSettingsToNVS() {
  prefs.begin("solartrk", false);
  prefs.putFloat("kp", (float)Kp);
  prefs.putFloat("ki", (float)Ki);
  prefs.putFloat("kd", (float)Kd);
  prefs.putInt("zonaMorta", zonaMorta);
  prefs.putInt("sogliaPM", sogliaPuntoMorto);
  prefs.putInt("sogliaNotte", sogliaNotte);
  prefs.putBool("pmAbil", puntoMortoAbilitato);
  prefs.putFloat("calTL", calTL);
  prefs.putFloat("calTR", calTR);
  prefs.putFloat("calBL", calBL);
  prefs.putFloat("calBR", calBR);
  prefs.end();
}

/**
 * Calibrazione dei 4 LDR
 */
void calibrateLDRs() {
  const int N = 10;
  long sumTL = 0, sumTR = 0, sumBL = 0, sumBR = 0;
  for (int i = 0; i < N; i++) {
    sumTL += readLDROversampled(ldrTL);
    sumTR += readLDROversampled(ldrTR);
    sumBL += readLDROversampled(ldrBL);
    sumBR += readLDROversampled(ldrBR);
    delay(20);
  }
  float avgTL = sumTL / (float)N, avgTR = sumTR / (float)N;
  float avgBL = sumBL / (float)N, avgBR = sumBR / (float)N;
  float avgAll = (avgTL + avgTR + avgBL + avgBR) / 4.0f;

  calTL = (avgTL > 1.0f) ? (avgAll / avgTL) : 1.0f;
  calTR = (avgTR > 1.0f) ? (avgAll / avgTR) : 1.0f;
  calBL = (avgBL > 1.0f) ? (avgAll / avgBL) : 1.0f;
  calBR = (avgBR > 1.0f) ? (avgAll / avgBR) : 1.0f;

  Serial.printf("[CALIBRAZIONE LDR] TL:%.3f TR:%.3f BL:%.3f BR:%.3f\n", calTL, calTR, calBL, calBR);

  saveSettingsToNVS();
}


void relayStep(RelayAxisState &st, double error, unsigned long nowMs, void (*setServo)(double)) {
  if (st.done) return;

  // Aggiorna l'estremo raggiunto nel semiciclo corrente
  if (st.relayDir > 0) {
    if (error > st.halfCyclePeak) st.halfCyclePeak = error;
  } else {
    if (error < st.halfCyclePeak) st.halfCyclePeak = error;
  }

  // Commutazione del relè: isteresi per non scattare su un attraversamento
  // dello zero dovuto solo a rumore residuo del segnale d'errore.
  bool shouldSwitch = (st.relayDir > 0) ? (error < -RELAY_HYSTERESIS) : (error > RELAY_HYSTERESIS);
  if (shouldSwitch) {
    st.halfCycleIndex++;
    unsigned long duration = nowMs - st.lastSwitchMs;

    if (st.halfCycleIndex > RELAY_DISCARD_HALFCYCLES) {
      // Il semiciclo appena concluso 
      if (st.relayDir > 0) { st.posPeakSum += st.halfCyclePeak; st.posPeakCount++; }
      else { st.negPeakSum += st.halfCyclePeak; st.negPeakCount++; }
      st.periodSumMs += duration;
      st.periodCount++;
    }

    if (st.halfCycleIndex >= RELAY_DISCARD_HALFCYCLES + RELAY_COLLECT_HALFCYCLES) {
      st.done = true;
    }

    st.relayDir = -st.relayDir;
    st.halfCyclePeak = error;
    st.lastSwitchMs = nowMs;
  }

  setServo(st.relayDir * RELAY_AMPLITUDE);
}
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
void loop() {
  // Gestione delle richieste dagli smartphone collegati al WebServer
  server.handleClient();

  readINASensors();

  // 0. Aggiornamento cinematica posizione virtuale e velocità H/V
  unsigned long nowPos = millis();
  float dt = (nowPos - lastPosUpdate) / 1000.0f;
  if (dt > 1.0f) dt = 0.01f;
  lastPosUpdate = nowPos;

  if (activeSpeedH != 0) {
    posH += activeSpeedH * SPEED_TO_DEG_PER_SEC * dt;
    while (posH >= 360.0f) posH -= 360.0f;
    while (posH < 0.0f) posH += 360.0f;
  }
  if (activeSpeedV != 0) {
    posV += activeSpeedV * SPEED_TO_DEG_PER_SEC * dt;
    if (posV > V_ANGLE_MAX) posV = V_ANGLE_MAX;
    if (posV < V_ANGLE_MIN) posV = V_ANGLE_MIN;
  }

  // 1. Lettura Sensori LDR  e Calcolo Diagonali
  float rawTL = readLDROversampled(ldrTL) * calTL;
  float rawTR = readLDROversampled(ldrTR) * calTR;
  float rawBL = readLDROversampled(ldrBL) * calBL;
  float rawBR = readLDROversampled(ldrBR) * calBR;

  if (!ldrFilterInit) {
    // Al primo giro il filtro parte dal valore letto, non da 0, per non introdurre
    // un transitorio artificiale all'avvio.
    filtTL = rawTL; filtTR = rawTR; filtBL = rawBL; filtBR = rawBR;
    ldrFilterInit = true;
  } else {
    
    float alpha = dt / (LDR_FILTER_TAU_S + dt);
    filtTL += alpha * (rawTL - filtTL);
    filtTR += alpha * (rawTR - filtTR);
    filtBL += alpha * (rawBL - filtBL);
    filtBR += alpha * (rawBR - filtBR);
  }
  valTL = (int)round(filtTL);
  valTR = (int)round(filtTR);
  valBL = (int)round(filtBL);
  valBR = (int)round(filtBR);

  valDiag1 = valTL + valBR; // Diagonale 1: Top-Left + Bottom-Right
  valDiag2 = valTR + valBL; // Diagonale 2: Top-Right + Bottom-Left
  diffDiagonali = valDiag1 - valDiag2; // Differenza tra le due diagonali

  int mediaTop = (valTL + valTR) / 2;
  int mediaBottom = (valBL + valBR) / 2;
  mediaTotale = (mediaTop + mediaBottom) / 2;

  // 2. Lettura e Calcolo Rendimento Solare (Voltage Divider / Sensore)
  int rawADC = analogRead(pinSolarVolt);
  // Lettura reale della tensione solare dal pin (Partitore R1=10k, R2=10k)
  solarVoltage = (rawADC / 4095.0) * 3.3 * 2.0; 
  
  // Se la tensione letta è trascurabile (< 0.1V), considera il pannello scollegato (0V, 0mA)
  if (solarVoltage < 0.1) {
    solarVoltage = 0.0;
    solarCurrent = 0.0;
  } else {
    // Stima della corrente erogata in base alla luminosità (max 500mA per il pannello)
    solarCurrent = (mediaTotale / 4095.0) * 500.0;
  }
  
  solarPower = (solarVoltage * solarCurrent) / 1000.0; // In Watt

  // Calcolo accumulo energia (Wh)
  unsigned long now = millis();
  float deltaHours = (now - lastEnergyCalc) / 3600000.0;
  lastEnergyCalc = now;
  totalEnergyWh += solarPower * deltaHours;
  realEnergyWh += (inaPanelP_mW / 1000.0f) * deltaHours;
  efficienzaPercent = (inaPanelP_mW > 0.1f) ? (inaLoadP_mW / inaPanelP_mW * 100.0f) : 0.0f;


  if (now - lastEnergySaveMs >= ENERGY_SAVE_INTERVAL_MS) {
    lastEnergySaveMs = now;
    prefs.begin("solartrk", false);
    prefs.putFloat("energyWh", totalEnergyWh);
    prefs.putFloat("realEnergyWh", realEnergyWh);
    prefs.end();
  }

  // 3. Esecuzione Logica in base alla Modalità Selezionata da Smartphone
  switch (currentMode) {

    case MODE_AUTO: {
      runAutoTracking();
      break;
    }

    case MODE_DOE: {
      if (doeActive && doeKicking) {
        if (millis() - doeKickStartMillis >= DOE_KICK_DURATION_MS) {
          doeBeginLogging(doeCurrentIndex);
        }
      } else {
        runAutoTracking();
        if (doeActive && !doeRunReady && (millis() - doeRunStartMillis >= doeRunDurationMs)) {
          stopServos();
          loggingActive = false;
          doeRunReady = true;
        }
      }
      break;
    }

    case MODE_MANUAL: {
      puntoMortoAttivo = false;
      if (millis() - lastManualCmdMillis > MANUAL_TIMEOUT_MS) {
        stopServos();
        manualVelH = 0;
        manualVelV = 0;
        inputH = 0;
        inputV = 0;
        outputH = 0;
        outputV = 0;
      } else {
        setServoH(manualVelH);
        setServoV(manualVelV);
        inputH = 0;
        inputV = 0;
        outputH = manualVelH;
        outputV = manualVelV;
      }
      break;
    }

    case MODE_AUTOTUNE: {
      isAutotuning = true;
      double newKp, newKi, newKd;
      if (runRelayAutotune(newKp, newKi, newKd)) {
        Kp = constrain(newKp, 0.0, 50.0);
        Ki = constrain(newKi, 0.0, 50.0);
        Kd = constrain(newKd, 0.0, 50.0);
        pidH.SetTunings(Kp, Ki, Kd);
        pidV.SetTunings(Kp, Ki, Kd);
        saveSettingsToNVS();
      }
      isAutotuning = false;
      currentMode = MODE_AUTO;
      modeString = "auto";
      resetPID(pidH);
      resetPID(pidV);
      pidActiveH = false;
      pidActiveV = false;
      break;
    }
  }

  // Campionamento log CSV in RAM, a intervallo configurabile
  // indipendente dalla velocità del loop.
  if (loggingActive) {
    unsigned long tNow = millis();
    if (tNow - lastLogSampleMillis >= logIntervalMs) {
      lastLogSampleMillis = tNow;
      if (logCount < MAX_LOG_SAMPLES) {
        LogSample &s = logBuffer[logCount++];
        s.t = tNow - logStartMillis;
        s.errH = (int16_t)inputH;
        s.errV = (int16_t)inputV;
        s.pulseH = (int16_t)lastPulseHus;
        s.pulseV = (int16_t)lastPulseVus;
        s.tl = (int16_t)valTL;
        s.tr = (int16_t)valTR;
        s.bl = (int16_t)valBL;
        s.br = (int16_t)valBR;
        s.vPanel_mV = (int16_t)(inaPanelV * 1000.0f);
        s.iPanel_mA = (int16_t)inaPanelI_mA;
        s.vLoad_mV = (int16_t)(inaLoadV * 1000.0f);
        s.iLoad_mA = (int16_t)inaLoadI_mA;
      } else {
        loggingActive = false; // buffer pieno, stop automatico
      }
    }
  }

  // Monitor Seriale Debug (ogni 500ms)
  static unsigned long lastPrint = 0;
  if (millis() - lastPrint > 500) {
    lastPrint = millis();
    Serial.printf("[Mode: %s%s] LDR(TL/TR/BL/BR): %d/%d/%d/%d | Diag1/Diag2/Diff: %d/%d/%d | Volt: %.1fV | Watt: %.2fW\n",
                  modeString.c_str(),
                  puntoMortoAttivo ? " (PUNTO MORTO!)" : "",
                  valTL, valTR, valBL, valBR,
                  valDiag1, valDiag2, diffDiagonali,
                  solarVoltage, solarPower);
  }

  if (WiFi.status() == WL_CONNECTED && (millis() - lastThingspeakSendMillis >= THINGSPEAK_INTERVAL_MS)) {
    lastThingspeakSendMillis = millis();
    sendToThingSpeak();
  }
}

// Setup Rotte WebServer
void setupWebServer() {
  // Pagina Principale HTML5
  server.on("/", HTTP_GET, handleRoot);

  // API REST Telemetria in tempo reale JSON
  server.on("/api/data", HTTP_GET, handleApiData);

  // API Cambia Modalità (mutante: solo POST)
  server.on("/api/mode", HTTP_POST, handleApiMode);

  // API Comandi Manuali D-Pad (mutante: solo POST)
  server.on("/api/control", HTTP_POST, handleApiControl);

  // API Aggiornamento Taratura PID, Soglie e Deadlock (mutante: solo POST)
  server.on("/api/pid", HTTP_POST, handleApiPID);

  // API Calibrazione dei 4 LDR sotto luce uniforme (mutante: solo POST)
  server.on("/api/calibrate", HTTP_POST, handleApiCalibrate);
  server.on("/api/resetpos", HTTP_POST, handleApiResetPos);

  // API Logging CSV in RAM: avvio/stop (mutanti, POST) e lettura stato/export (GET)
  server.on("/api/log/start", HTTP_POST, handleApiLogStart);
  server.on("/api/log/stop", HTTP_POST, handleApiLogStop);
  server.on("/api/log/status", HTTP_GET, handleApiLogStatus);
  server.on("/api/log/csv", HTTP_GET, handleApiLogCsv);

  // API Autotuning PID (Relay Feedback) On-Demand (mutante: solo POST)
  server.on("/api/autotune", HTTP_POST, handleApiAutotune);

  server.on("/api/ina/config", HTTP_POST, handleApiInaConfig);
  server.on("/api/ina/scan", HTTP_GET, handleApiInaScan);

  server.on("/api/doe/upload", HTTP_POST, handleApiDoeUpload);
  server.on("/api/doe/start", HTTP_POST, handleApiDoeStart);
  server.on("/api/doe/next", HTTP_POST, handleApiDoeNext);
  server.on("/api/doe/stop", HTTP_POST, handleApiDoeStop);
  server.on("/api/doe/status", HTTP_GET, handleApiDoeStatus);

  // Gestione errore 404
  server.onNotFound([]() {
    server.send(404, "text/plain", "404: Not Found");
  });
}

void handleRoot() {
  server.send_P(200, "text/html", index_html);
}
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

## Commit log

2026-08-31 Aggiunta primo Paper
    Il paper riguarda l'utilizzo di sistemi di solar tracking per migliorare l'efficienza di moduli fotovoltaici
2026-09-01 Piccolo errore di sintassi
2026-09-09 prototype section in README
    Restored the prototype section in the README with details about material choices and circuit assembly.
2026-09-09 Update README with final print details
    Added section for 'Stampa Definitiva' and updated table of contents.
2026-09-13 Refine README content and remove TODOs
    Removed TODO comments and updated PID tuning method description. Adjusted content structure and clarified repository structure.
2026-09-13 Definitive Images
    [run34_dz500_rep4.csv]
2026-09-13 Update README with solar panel and circuit information
    Added details about the solar panel and circuit components.
2026-09-15 Added 3D
    [base_rettangolare.step, croce_ldr.step, forcelle.step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]
